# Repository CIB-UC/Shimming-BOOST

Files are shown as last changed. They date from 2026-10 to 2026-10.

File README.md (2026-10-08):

# BOOST — Low-Field MRI Shimming Tool

A plain-language guide.

**Who this is for:** anyone using this tool — you do **not** need to know programming.
This guide explains, in everyday language, what the tool does and the newest
things it can do. Every technical word is explained in the **Glossary** at the end.

For the deep technical details (architecture, config, code layout), see
[`docs/TECHNICAL_REFERENCE.md`](docs/TECHNICAL_REFERENCE.md). This
document is the friendly version.

**Getting started** (needs Julia and an NVIDIA GPU; once per computer, then each time you want the web page):

```bash
julia install_deps.jl      # one-time setup
julia gui/server.jl        # then open http://localhost:8010
```

---

## 1. What the tool does, in 30 seconds

An MRI magnet needs a very even magnetic field in the space where the sample or
patient goes. Straight out of the box, the field is a bit lumpy. We smooth it out by
placing lots of small magnets ("shims") in printed trays around the tube, and rotating
each one to just the right angle so their combined nudges cancel the lumps.

The tool does this in steps:

- **Stage 0 — Field map:** read a measurement of the current (lumpy) field.
- **Stage 1 — Optimize:** calculate the best angle for every shim magnet.
- **Stage 1.5 — Export:** write those results into a simple table (a list of magnets, positions, and angles).
- **Stage 2 — Inserts / STL:** turn that table into 3D files you can print.
- **Stage 3 — Verify:** look at the result in 3D.
- **Stage 4 — Python check:** an independent second opinion — a separate program
  recomputes the shimmed field and reports the score, pictures and spherical harmonics.

You normally drive all of this from a **web page** on your own computer: you start it
(a colleague can show you the one command), and it opens in your browser at
`http://localhost:8010`. Everything below is done by clicking in that page.

At the very top of the page there are two boxes: **Iteration name** and **Label #**.
Whatever you type there names your run — it becomes the output folder's name and the
number engraved on the printed trays. Set these first, every time.

---

## 2. The new features (overview)

1. **Insert search** — tell it how many magnets you own; it decides, one insert at a
   time, where each should go and how each magnet in it should be turned.
2. **OSII import** — you already have a magnet layout from the OSII program? Skip our
   calculation entirely and go straight to printing.
3. **Score on real measurements** — let the calculation judge the field using your
   actual measured points instead of a smoothed computer model. More honest.
4. **Faster ring search** — the "find the best magnet positions for me" tool now runs
   in minutes (or seconds) instead of the better part of an hour.
5. **Look at the field before shimming** — open the viewers on the raw measured field,
   with no magnets needed, to inspect how uneven it is up front.
6. **Magnet strength is now a setting** — type in your magnet's remanence and size
   instead of it being fixed in the code.
7. **Save a GIF of the result** — both viewers can now export an animated GIF of what
   you're looking at, so you can share it without asking someone to run the tool.

8. **Independent Python check (Stage 4)** — a separate program double-checks the result
   with its own physics, so you don't have to trust the optimizer's own arithmetic.

9. **Spherical-harmonic breakdown of the measured field (Stage 0)** — see which "field
   shapes" make up the unevenness, and optionally rebuild the field from only the first few
   degrees or only the biggest few shapes.

10. **Frames made explicit** — the magnet list is now turned back into your scanner's own directions,
    and both viewers draw (and sign) the field the same way. Plus **Halbach test bits** to check your axes.

Each is explained in full below.

---

## 3. Feature 1 — Insert search (place one insert at a time)

### What it's for

The ring search fills a whole **ring** at once — all 12 trays, 84 magnets. That is a
lot of magnets, and you may not have that many. Insert search works in the unit you
actually buy and print: **one insert** — one tray at one ring position, holding 7
magnets.

You tell it how many magnets you have. It works out how many full inserts that is
(magnets ÷ 7, rounded down — an insert is never planned half-empty), and then places
them one at a time.

### How it decides

1. It tries every empty, legal slot — every tray at every candidate ring — and for
   each one works out the best rotations for its 7 magnets.
2. It keeps the single best slot and fixes it in place.
3. It then treats those 7 magnets as **part of the magnet**, not as something still
   being decided, and goes looking for the next insert against that new situation.

So each insert is chosen knowing exactly what the previous ones did. Earlier inserts
are never re-turned, which is what makes this different from the ring search.

### The spacing rule

Two inserts **in the same tray** must have at least a few empty ring slots between
them (setting: `insert_search_min_spots_between`), because they'd otherwise collide.
Inserts in *different* trays are separate printed pieces, so they can sit at the same
ring position with no problem.

### Something important about using all your magnets

A shim magnet can be **rotated, but not switched off**. So adding one more insert is
not automatically an improvement — sometimes the extra magnets do more harm than good.

The tool therefore places your whole budget, records the score after every single
insert, and then tells you which point was actually best. If inserts 10 to 12 made
things worse, it says so, and the layout it hands you contains only the first 9. You
use fewer magnets *and* get a better field.

### How to use it — step by step

1. Open the web page and set **Iteration name** and **Label #** at the top.
2. Run **Stage 0 "Prepare field map"** as usual.
3. In the **"1 — Optimize"** box, pick the **"Insert search (per-slot)"** task.
4. Type your magnet count into **`magnets_available`**. The line underneath tells you
   how many full inserts that is, and how many magnets would be left over.
5. Click **"Run optimization."** Watch the log: one line per insert, showing where it
   went and the score afterwards.
6. When it finishes, read the **BEST PREFIX** line — that is what it kept.
7. Go to **"2 — Inserts / STL"** and click **"Build STL only."**

### Where to see what it decided

- The **"3 — Verify & output"** box lists each printed ring *and which trays actually
  carry magnets* — so you can see at a glance that, say, Ring_N07 holds only trays 2 and 7.
- `InsertSearch/insert_search.png` plots the score against the number of inserts, with
  the best point marked.
- `InsertSearch/insert_search.csv` lists every step, with a `kept` column.

---

## 4. Feature 2 — Importing an OSII layout

### What it's for

Sometimes another program (called **OSII**) has *already* decided where the magnets go
and how each should be rotated. In that case you don't need our tool to figure it out —
you only need to turn OSII's answer into printable trays. This feature does exactly
that, letting you jump in near the end of the process.

### What it actually does

It reads OSII's file and rewrites it in the format our tray-builder understands. Think
of it as a translator between two languages that describe the same thing.

### Why a translation is needed (the honest details, in plain terms)

OSII and our tool both locate each magnet with three numbers (like describing a spot by
its left–right, up–down, and front–back distances), and both give each magnet a
rotation angle. But they don't label the directions the same way, and they use
different units. So the tool automatically:

- **Converts the units** — OSII uses metres, we use millimetres (every distance is
  multiplied by 1000).
- **Matches up the directions** — one axis is the same in both; the other two are
  swapped, and one is flipped. The practical result: the ring of magnets OSII describes
  lands in the correct plane in our system, at its real, physical tray-slot number —
  positive going toward the wall end, negative going toward the gaussmeter end,
  counted outward from the centre of the tube.
- **Adjusts each magnet's rotation** — the two programs measure a magnet's turn from a
  different starting line **and** in opposite directions, so the tool flips the turn and
  adds a fixed quarter-turn (90°).

You don't do any of this by hand. But two settings let you correct the rotation if a
test print ever comes out turned the wrong way:

- **`osii_invert_angle`** (on by default) — flips the *direction* of the turn. If the
  magnets look **mirrored**, toggle this.
- **`osii_angle_offset_deg`** (90 by default) — the fixed extra turn. If every magnet
  looks rotated by the **same amount**, change this number.

Both are adjustable right in the web page, so a fix is a click away — no code.

### How to use it — step by step

1. Open the web page.
2. At the top, type your **Iteration name** and **Label #**. These will appear on the
   output folder and be engraved on the trays.
3. Find the box labelled **"1.5 — OSII import."**
4. In **"Use OSII file,"** pick your OSII file. (Not listed? Paste its full path into
   **"Import CSV (full path)"** and click **"Import into OSII folder"** — then pick it.)
5. Leave the **Transform** settings at their defaults the first time (invert on, offset 90).
6. Click **"Convert OSII → shim CSV."**
7. Go to the box labelled **"2 — Inserts / STL"** and click **"Build STL only."**
8. Your printable trays appear in the output folder, named with your iteration.

### Important: which Stage 2 button to press

Stage 2 has **two** buttons:

- **"Build STL only"** — use this after an OSII import (the magnet list already exists).
- **"Export + build STL"** — use this only after you've run our optimizer.

If you press "Export + build STL" after an OSII import, it will fail with a
"file not found" error — because that button first tries to export an optimizer result
that doesn't exist (you skipped the optimizer on purpose). **After OSII import, always
use "Build STL only."**

---

## 5. Feature 3 — Scoring on your real measurements

### The idea

Before the tool can improve the field, it has to measure how uneven the field is. It
checks the field at many points on the surface of an imaginary sphere (called the
**shell**) the size of your imaging region. There are now two ways to get those check
points:

- **`measured`** (new, and now the default) — use the *actual* points your scanner
  measured, with their *actual* readings. Nothing is invented or smoothed.
- **`sh_fibonacci`** (the older way) — build a smooth mathematical model that best fits
  your measurements, then read that model at a set of evenly spaced, invented points.

### Why "measured" is usually better

The smooth model quietly rounds off the sharpest bumps in the real field. On your last
scan, the smoothed version reported the field spread as about **18,050 ppm**, but your
real measured points showed about **18,255 ppm** — the smoothing was hiding roughly
**200 ppm** of genuine unevenness. It's better to improve the field against the honest
number. And because your scan already sits neatly on the sphere, using the real points
is both possible and more faithful.

**When would you keep `sh_fibonacci`?** If your measurement is scattered or doesn't sit
on a clean sphere, or if you specifically want a set of perfectly evenly spaced points.

### How to use it

In the **"0 — Field map"** box, under **"Field adapter,"** set **`shell_source`** to
`measured` (it's already set for you). Click **"Prepare field map."** You'll see a line
in the log like `shell: 1742 MEASURED points (no interpolation)`. Then run the optimizer
as usual. If instead you see `... SH-fit points ... (interpolated)`, you're on the old
mode — switch the dropdown.

---

## 6. Feature 4 — A faster "ring search"

### What ring search is

Instead of *you* choosing which tray positions ("rings") to fill with magnets, ring
search tries combinations and reports the best set. It has two styles:

- **Exhaustive** — literally tries *every* possible combination. Thorough, but slow.
- **Paired** — only tries *symmetric* layouts, where every ring on one side of the
  centre has a twin at the same number on the other side (for example rings −10, −5, +5
  and +10). You say how many rings you want in total (it must be an even number: 4 rings
  = 2 pairs), and it tries **every** possible combination of pairs. Because it only
  considers symmetric layouts there are far fewer to try (300 for 4 rings across ±25),
  so it is quick and thorough at once. The individual magnets are still turned freely —
  only the *ring positions* are paired. Two twins are exactly mirror images in
  distance only if the front and back tray distances are equal.
- **Greedy** — builds the set up one ring at a time, always adding the most helpful
  next ring. Almost always lands on the same (or nearly the same) answer, much faster.

### What was slow, and what we fixed

Trying every group of 4 rings out of 50 candidates is about **103,000 trial fits**, and
each was taking around 26 milliseconds — so the whole thing would run about **45
minutes**. We fixed two things:

- The trial fits were running in a slower numeric mode; we switched to the fast one.
- The big win: each trial was checking the field at all 1,742 points, but for merely
  *ranking* which group is best, a few hundred points give the same ordering. So ranking
  now uses about 250 points, and only the single winning group is re-checked on the full
  set. That's roughly **10–35× faster** per trial, with no meaningful change to the
  answer.

Exhaustive now takes about **3–5 minutes** instead of 45.

### The practical advice

For a search this size, **use "greedy."** It does about 200 trials instead of 103,000 —
so it finishes in **seconds** — and almost always finds the same answer. Choose it in
the **"1 — Optimize"** box: pick the **"Ring search (best n)"** task and set the method
to **greedy**. Only use exhaustive if you specifically need the guaranteed-best group.

### Watching it run

While it works, the log now prints `1000 scored`, `2000 scored`, and so on, so you can
see progress. (Previously a display quirk hid these updates until the very end — that's
fixed.)

---

## 7. Feature 5 — Looking at the field — before or after shimming

### What it's for

You don't have to shim before you can *see* the field. The two viewers now open on the
**raw measured field** on their own, so you can check how uneven it is right after
measuring — before deciding anything. (Once you've shimmed, the same viewers also show
the shimmed result, as before.)

### The two viewers

- **Slice viewer** — a flat "map" of the field through a chosen plane, plus a line
  profile across it and a homogeneity number (ppm). Best for judging uniformity.
- **3D viewer** — a 3-D cloud of the field (and, once shimmed, the magnets too).

### How to open the field on its own

1. Run **Stage 0 "Prepare field map."**
2. In the **"3 — Verify & output"** box, click **"Open slice viewer"** (or "Open 3D
   viewer"). With no shim yet, they come up showing only the measured field — the title
   says "pre-shim." No optimization, no magnets required.

### Handy tools inside the slice viewer

- **Zoom into a region** (drag/scroll) to focus on the client's region of interest. The
  zoom now **stays put** when you move the sliders, the **ppm updates to that region only**
  (it says "visible region"), and the line profile **clips to the region** too — so you're
  always looking at just the part that matters.
- **Sphere mask:** a button crops the view (and the ppm) to a sphere of a chosen radius,
  hiding the corners that are usually the least trustworthy.
- The field is now sampled every **5 mm** for smoother pictures.

---

## 8. Feature 6 — Saving a GIF of the result (new)

### What it's for

Once you've got a view you like in the 3D viewer or the slice viewer — a good angle,
a good slice, the shimmed result — you can save it as an animated GIF instead of
taking a screenshot or asking a colleague to open the tool themselves.

### The two kinds

- **3D viewer** — "Save GIF" spins the camera a full 360° around the bore at
  whatever elevation/distance you've currently zoomed/rotated to, and saves that
  as a GIF.
- **Slice viewer** — "Save GIF" instead sweeps the slice position across the field
  (a "slice sweep"), so you see the field change plane by plane.

Each viewer also has a second button, **"Save GIF pair: Measured vs Shimmed,"**
which saves two matching GIFs side by side — one of the raw measured field, one of
the shimmed result — for a clean before/after.

### Where the files go

GIFs are saved under your iteration's output folder, in a `Viewers` subfolder
(`data/outputs/Optimizer_Output_per_Iteration/<your iteration>/Viewers/`). Two settings control
length: how many frames, and how many frames per second — by default a GIF is
120 frames at 20 frames/second, i.e. 6 seconds long.

---

## 9. Feature 7 — Independent Python check (Stage 4)

### What it's for

The optimizer predicts a score (ppm) for your magnet layout, but it uses its own
calculation to do so. Stage 4 hands the same layout to a **separate program** (written
in Python, in the `Shimming_verifier` folder) that calculates the magnets' field a
different way. If both programs agree, you can trust the number. On the reference run
the optimizer predicted about 9,480 ppm and the Python check found about 9,560 ppm
(the unshimmed field was about 18,540 ppm).

### What you choose

Only three things — everything else (magnet strength, size, units) is taken from the
settings you already made:

1. **Which field** — the measured scan to compare against. Leave it on
   *"same as Stage 0 field map"* unless you want a different scan.
2. **Which shim layout** — normally this run's magnet list (from the optimizer, the
   insert search or an OSII import). Untick *verifier_use_shim* to look at the measured
   field alone, without any shim magnets.
3. **What to run** — any of: 2D pictures of the field with vs without shim, an
   interactive 3D scene (opens in any browser), and the spherical-harmonic pyramids
   (how much of each "field shape" the shim removes).

### How to use it

1. Finish your run (you need a shim CSV, so at least Stage 1.5 or an insert search).
2. In the **"4 — Python verifier"** box, check the three choices above.
3. Click **"Run verifier."** It takes a few seconds; the log ends with the
   with/without-shim scores and where the files went.
4. Click **"Open verifier output"** to see the pictures and open `scene_3d.html`.

You can also make it run automatically at the end of a full run (*run_python_verifier*),
or run only this stage from the command line by setting `start_stage = 5`.

### First-time setup

The Python program needs a few Python packages. Once, in a terminal:
`python -m pip install -r stages/stage4_verifier/Shimming_verifier/requirements.txt`. If Python isn't on
your PATH, put its full path in *verifier_python*.

---

## 9a. Feature 9 — Spherical-harmonic breakdown at Stage 0

### What it's for

Any uneven field can be split into standard "shapes" called spherical harmonics, each with
a *degree* n (1 = a simple slope, 2 = a saddle/bow shape, then finer and finer detail) and a
strength in mT. Stage 0 now shows this breakdown for your measured field every time it
builds the field map, so you can see at a glance which shapes dominate — and therefore what
the shims actually have to fight.

### What you see

In the run log, after Stage 0: the average field, a short table of how strong each degree
is, and **a list of the 5 biggest shapes** (say how many with *sh_top_k*), each with its
share of the total unevenness. A full table is saved next to your results
(`SHDecomposition/sh_decomposition.csv`).

### What you can choose (*sh_select*, Stage 0 → Field adapter)

- **all** (default) — use every shape the fit found. Nothing changes from before.
- **first_n** — keep only degrees 1…n (set *sh_use_degree*). Throws away the fine detail and
  keeps the broad shape.
- **top_k** — keep only the average plus the *sh_top_k* biggest shapes (for example 5).

With the last two, the optimizer and the viewers work on this **simplified** field, not the
raw measurement — so the ppm numbers you see afterwards describe the simplified field. The
log's last line tells you how far the simplified field is from your real data (RMS and ppm).
For the honest number, keep *all* and use the shim on the real field; use *first_n* / *top_k*
when you want to study or shim only the dominant shapes.

In shell mode with *shell_source = measured*, the same measured points are used, but their
values come from the simplified field when first_n / top_k is on.

---

## 9b. Feature 10 — Which way is the field pointing? (frames) and Halbach test bits

### The problem in plain words

Your scanner's axes (X, Y, Z) and the magnet's field direction don't have to line up. The tool
calculates in an internal "tidy" view where the field always points up (+y) — it quietly **turns** your
measurement to get there. Your scan says the field points along −y, so the tidy view is turned half a
turn (180°) compared with the scanner. That is fine for the maths, but the results (magnet positions and
angles) have to be turned **back** before they mean something in the scanner's own directions.

### What happens now (by default)

- Right after the optimizer, the magnet list is turned back into the **scanner's view** (`shim_csv_frame
  = "scan"`). The printed trays, both viewers and the Python check then all use the scanner's view.
- Both viewers draw in the scanner's view too (`viewer_frame = "scan"`) and show the field **with its sign**
  (negative numbers if the field points −x or −y). Set either key to `"optimizer"` (in `config.toml`) to get
  the old behaviour.
- A magnet list made **before** this change is not converted — just click **Export** again (no need to
  re-optimize).
- Tray numbers are worked out from where each magnet sits, so after the turn a −y scan's tray 3 becomes tray 9
  and so on (every tray shifts by 6). Check that the physical tray numbering on your magnet matches the
  scanner's directions — this is the one thing the tool cannot know for you.

### How well was it checked?

An independent calculation on your real −y scan showed the turned-back layout cuts the unevenness from
about 19,200 ppm to about 9,600 ppm, while using the un-turned list made it worse (about 28,800 ppm). It
cannot tell front from back (the rings are nearly symmetric), so a mirrored z axis would not show up. The
viewers and the export step themselves have not been run since this change.

### Halbach test bits (checking your axes without the optimizer)

`make_halbach_ring_csv.py` writes a small magnet list that imitates a Halbach ring, so you can see in the
viewers and the Python check whether directions come out as expected. You choose the OSII version (OSII2: field
+y, OSII1: field +x), which tray(s), where along the bore (a z in mm, or a slot number) and how many
positions (an odd number). To make STLs from it: copy it into a **new** iteration folder as `<iteration>_shim.csv`
and use **Build STL only**.

## 10. Glossary

- **Shim (shim magnet)** — a small magnet added to nudge the main field toward being even.
- **Ring** — one position along the tube where a full circle of shim magnets sits. In this setup a full ring holds 84 magnets.
- **Insert position (InsertPos)** — the real, physical slot number for a ring, counted
  outward from the centre of the tube: positive toward the wall end, negative toward
  the gaussmeter end (e.g. `-7` or `12`). This is what "Ring number" actually means
  everywhere in the tool now — it is never just a count of "which ring is this in
  the current run" — and it's what gets engraved on the printed part.
- **N / P label** — how a negative or positive insert position is written on a
  printed part and in folder/file names, since a printed minus sign is easy to
  misread or lose: `N07` means insert position `-7`, `P12` means `+12`.
- **Tray** — the 3D-printed holder that carries the magnets for one part of a ring.
- **Insert** — one tray's worth of magnets at one ring position: 7 magnets. The unit the insert search places, and the unit you print.
- **Front / Back** — Front is the gaussmeter end of the tube, Back is the wall end. Their distances from the centre are set separately, because the magnet isn't symmetric.
- **Bore / imaging region / DSV** — the tube (and the space inside it) where the sample or patient goes; the region we want to be even.
- **Field uniformity / ppm** — a score for how even the field is. "ppm" means *parts per million*. It's the gap between the strongest and weakest field, divided by the average, times a million. **Lower is better.**
- **Shell** — the surface of an imaginary sphere where we check the field. Thanks to physics, if the field is even on this surface, it's even everywhere inside — so checking the surface is enough.
- **Optimizer** — the part of the tool that calculates the best magnet angles.
- **Field map** — the tool's internal picture of the current field, built from your measurement.
- **CSV** — a plain table file, like a spreadsheet saved as simple text.
- **STL / STEP** — 3D-model file formats: STL for printing, STEP for CAD editing.
- **Iteration** — one named run. Its name labels the output folder and is engraved on the printed trays.
- **Stage 0 / 1 / 1.5 / 2 / 3 / 4** — the steps of the process: read the measurement (0), calculate angles (1), write the magnet list (1.5), make printable trays (2), view/verify (3), independent Python double-check (4).
- **magpylib** — the Python physics library the Stage 4 check uses to compute each magnet's field. Separate from the optimizer's own code, which is the point.
- **Spherical harmonics (SH) pyramid** — a chart splitting the field's unevenness into standard "shapes" (degree 1, 2, 3 …). Shows *which* shapes the shim removes and which remain.

- **Scan frame (scanner view)** — the X, Y, Z directions of your measurement file.
- **Optimizer frame (tidy view)** — the internal view where the field always points along +y; the optimizer works here.
- **Halbach ring** — magnets turned in a regular pattern (angle = twice the position angle) so their fields add up inside the ring.

---

## 11. Quick reference — where each new setting lives

| Setting | Where in the web page | Plain meaning |
|---|---|---|
| `shell_source` | Stage 0 → Field adapter | Use real measured points (`measured`) or a smoothed model (`sh_fibonacci`). |
| OSII file | Stage 1.5 → OSII import | Which OSII layout file to convert. |
| `osii_invert_angle` | Stage 1.5 → Transform | Flip magnet turn direction if a print looks mirrored. |
| `osii_angle_offset_deg` | Stage 1.5 → Transform | Fixed extra turn (90°); change if a print is rotated by a constant amount. |
| Ring search method | Stage 1 → Ring search task | `greedy` (fast, recommended), `exhaustive` (thorough, slow) or `paired` (only symmetric ±pairs, every combination). For `paired`, the ring count is the total and must be even. |
| `magnets_available` | Stage 1 → Insert search task | How many shim magnets you own. Divided by 7 to get the number of full inserts. |
| `insert_search_min_spots_between` | Stage 1 → Insert search task | How far apart two inserts must be *within the same tray*. |
| `magnet_Br_T` | Stage 0 → Shim magnets | How strong one magnet's material is: its remanence, in tesla (from the datasheet). |
| `magnet_side_mm` | Stage 0 → Shim magnets | The physical cube side length of one magnet, in mm. |
| `letter_thickness` | Stage 2 → Insert params | How deeply the label digits are engraved into the printed part. |
| `label_scale` | Stage 2 → Insert params | Overall size of the engraved label digits (iteration, insert position, tray). |
| `viewer_gif_frames` / `viewer_gif_fps` | (config.toml; not yet a GUI field) | How many frames a Save-GIF export has, and how fast it plays — together set the length in seconds. |
| `sh_select` | Stage 0 → Field adapter | Build the field map from `all` shapes, only the `first_n` degrees, or only the `top_k` biggest. |
| `sh_use_degree` | Stage 0 → Field adapter | first_n: keep degrees up to this number. |
| `sh_top_k` | Stage 0 → Field adapter | top_k: how many biggest shapes to keep — and how long the "biggest shapes" list in the log is. |
| `verifier_measurement` | Stage 4 → Which field | Scan the Python check compares against (blank = the same as Stage 0). |
| `verifier_use_shim` / `verifier_shim_csv` | Stage 4 → Which shim layout | Include the shim magnets; blank path = this run's magnet list. |
| `verifier_make_2d` / `_3d` / `_sh` | Stage 4 → What to run | Which outputs to produce: 2D pictures, 3D scene, spherical-harmonic pyramids. |
| `run_python_verifier` | Stage 4 → What to run | Also run Stage 4 automatically at the end of a full run. |
| `front_tray_shift_mm` | Stage 0 → Geometry | Distance from the centre to the first tray on the gaussmeter side. |
| `back_tray_shift_mm` | Stage 0 → Geometry | Distance from the centre to the first tray on the wall side. |
| `tray_slot_spacing_mm` | Stage 0 → Geometry | Gap between neighbouring tray positions (10 mm). |
| `main_field_direction` | Stage 0 → Field adapter | Which way the field points in your scan (`auto` reads it from the measurement). |
| `shim_csv_frame` | (config.toml only) | `scan` (default): the magnet list is written in your scanner's view; `optimizer`: old internal view. |
| `viewer_frame` | (config.toml only) | `scan` (default): viewers draw in your scanner's view with a signed field; `optimizer`: old view. |

All of these can also be set by editing the `config.toml` file directly, but the web
page is the easy way and is recommended.

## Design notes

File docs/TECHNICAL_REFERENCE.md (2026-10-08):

# Low-Field MRI Shimming Pipeline — Technical Reference

Passive-shimming toolchain for a low-field Halbach MRI magnet (Pontificia
Universidad Católica de Chile — Low-Field MRI project). It takes a measured
magnetic-field map, computes the optimal angles for a set of small permanent
"shim" magnets that flatten the field, and produces 3D-printable tray inserts —
all driven from a single config file or a browser GUI.

```
measured CSV ──▶ field map ──▶ optimal shim angles ──▶ shim CSV ──▶ STL/STEP trays
   Stage 0          Stage 1          (Stage 1)          Stage 1.5      Stage 2

 measured CSV + shim CSV ──▶ independent Python (magpylib) check of the result
                                         Stage 4
```

Everything is organized as one **iteration**: name it, set parameters, run, get
printable parts plus a verification view.

---

## Part I — Project information

**The problem.** A Halbach array gives a strong-ish B₀ in the bore, but it is not
homogeneous enough for imaging. Passive shimming corrects this by placing many
small magnets on trays around the bore; rotating each magnet changes its field
contribution. The task is to choose all the angles so the field over a target
volume is as uniform as possible.

**The measurement.** B₀ is measured on a spherical shell (or a grid) with a
gaussmeter on a robot. The pipeline reads that scan, models the field, and scores
homogeneity as **ppm** = 10⁶ · (max − min) / mean over the target region.

**The key scientific result.** The shim field is *exactly linear* in the magnet
moments, so field variance is a smooth, convex function of the angles with an
analytic gradient. A gradient method (L-BFGS) therefore finds the **global**
optimum in seconds — and shows that the remaining inhomogeneity is a **hardware
limit**, not an optimizer limit. The lever from here is physical: more / stronger /
closer shim magnets, or more rings.

**Three headline capabilities beyond "solve for the angles":**
- **Ring search** — instead of telling it where to put rings, ask it to *find* the
  best set of *n* rings from a candidate range.
- **Insert search** — a finer granularity: place ONE insert at a time (one tray at
  one ring, `mags_per_segment` magnets), driven by how many magnets you actually
  own, freezing each choice before searching the next.
- **Shell evaluation** — score homogeneity on a single spherical shell at the DSV
  radius. Because the bore field is harmonic, min/max on that surface equal min/max
  over the whole ball, so range/ppm is exact with far fewer points.

---

## Part II — How it works

### Quick start

```bash
julia install_deps.jl        # once — pins the project (CUDA, GLMakie, Gmsh, Optim, HTTP, JSON, …)

# Option A — the GUI (recommended)
julia gui/server.jl          # opens http://localhost:8010

# Option B — terminal, one config-driven run
julia run_pipeline.jl        # runs Stage 0→1→1.5→2→3 (viewers)→4 per config.toml
```

Needs an NVIDIA GPU (CUDA) for Stage 1 and the viewers. Everything is driven by
**`config.toml`**; `pipeline_config.jl` reads it and derives every path + geometry,
so nothing can drift apart.

### The stages

| Stage | Script | Does |
|---|---|---|
| 0 | `Field_data_*` adapters | measured CSV → field map (`.jld2`) |
| 1 | `sim_annealing_optim/` **or** `grad_optim/` | field map → optimal shim-magnet angles |
| 1.5 | `export_csv.jl` | optimizer result → shim CSV (`X, Y, RingNumber, Angle`; `RingNumber` = real InsertPos) — the seam |
| 2 | `CSV_to_STL.jl` (Gmsh) | shim CSV → per-tray STL + STEP, + the static insert |
| 3 | `Shimming_magnets_visualizer.jl`, `field_slice_viewer.jl` | 3D magnet/field view, 2D slice + profile; each has a "Save GIF" button |
| 4 | `python_verifier.jl` → `stages/stage4_verifier/Shimming_verifier/run_verifier.py` | independent **Python/magpylib** re-computation of the shimmed field: ppm, 2D projections, 3D scene, spherical-harmonic pyramids |

`run_pipeline.jl` chains them as separate subprocesses (so CUDA/GLMakie and Gmsh
never share a process), checks each exit code + output, and stops at the first
failure. `start_stage` lets you jump in and reuse earlier outputs.

**Two shortcuts that skip the optimizer:** `osii_to_shim.jl` converts an existing
**OSII** magnet layout straight into the Stage-1.5 shim CSV (then Stage 2 runs as usual —
GUI button "Build STL only"), and both **Stage-3 viewers run with no shim CSV** — after
Stage 0 alone they show just the measured field (pre-shim) for homogeneity inspection.

### Stage 4 — independent Python verifier (`Shimming_verifier/`)

A self-contained Python tool (magpylib closed-form cuboid model — **no shared code with
the Julia kernels**) that takes the measured field and the shim layout, recomputes the
shim's field at the measured points, and reports the shimmed homogeneity. Because it is
a different model of the same magnets, agreement with the optimizer's ppm is a genuine
cross-check of the operator `G` (reference run: optimizer predicted 9483 ppm, verifier
9562 ppm, unshimmed 18538 ppm). It stays independent of the pipeline: it needs only
**which field, which shim layout, what to run**, and lives in its own folder
(`main.py` = interactive/VSCode entry, `run_verifier.py` = command-line entry, deps in
`requirements.txt`).

`python_verifier.jl` is the thin adapter (Julia stdlib only — no CUDA, no field map):
- **Inputs** — `verifier_measurement` (blank = the run's own scan) and the shim CSV
  (`verifier_use_shim`; blank `verifier_shim_csv` = this iteration's `_shim.csv`, i.e.
  whatever produced the seam: optimizer export, insert search or OSII import). The
  seam's `RingNumber` (the real InsertPos) is converted back to axial z with
  `ringpos_from_tray_mm` and the current tray-geometry keys; a CSV that already has a
  `Z (mm)` column (e.g. `export_csv.jl`'s `_shim_xyz.csv`) is accepted as-is.
- **What to run** — `verifier_make_2d` / `_3d` / `_sh` (+ `verifier_sh_max_degree`,
  `verifier_show_figures`).
- **Not repeated** — magnet strength/size come from `magnet_Br_T` / `magnet_side_mm`,
  the coordinate unit from `sh_measured_unit_mm`.
- **Frame.** Stage 0 rotates the scan so B0 → +y for the optimizer, so every shim CSV is
  in that frame, while the verifier reads the *raw* scan. `run_verifier.py
  --shim-frame optimizer` rotates the shim positions + angles back into the scan's frame
  using B0's direction (`main_field_direction`, or auto-detected from the scan's mean
  field vector). Identity for the current scanner (B0 = +y); checked with synthetic
  +x / −x / −y scans, which reproduce the +y result exactly. **Now** (`shim_csv_frame = "scan"`, the
  default) the seam CSV is already in the scan frame, so `python_verifier.jl` passes `--shim-frame lab`
  (CSV as written); with `"optimizer"` it still passes `--shim-frame optimizer`.
- **Outputs** → `data/outputs/Optimizer_Output_per_Iteration/<ITER>/PythonVerifier/`
  (`comparison_2d.png`, `scene_3d.html`, `sh_pyramid.png`, plus the derived shim input).
- **Running it** — GUI Stage 4 "Run verifier"; `julia stages/stage4_verifier/python_verifier.jl`;
  `start_stage = 5` (verifier only); or `run_python_verifier = true` to append it to a
  full run. Misalignment-study knobs (remanence spread, measurement/magnet shifts) exist
  on the CLI (`stages/stage4_verifier/python Shimming_verifier/run_verifier.py --help`) but default to 0.

### Stage 0 — reading the measurement

A shared reader, `utils/read_measured.jl`, handles **two spherical-scan CSV
formats** transparently:
- **simple** — metadata line 1, header line 2 (`X,Y,Z,Gauss`) — the original Josh scan;
- **"Controlled"** — a multi-line metadata block, then columns for `radio, theta,
  phi, X,Y,Z, T_robot, muestra, …, x/y/z axis (gauss), Magnitude (gauss)`.

It finds the data header wherever it is, **averages the repeated samples per point**
(`muestra`), uses `|B|` (the `Magnitude` column), and — when the scan recorded field
components — returns the mean `(Bx,By,Bz)` vector. Temperature is read but not used
yet.

Three Stage-0 adapters consume that:
- **`Field_data_file_adapter.jl`** (`field_adapter = :reshape`) — a complete regular
  (parallelepiped) grid; just reshapes it.
- **`Field_data_SH_interpolator.jl`** (`:spherical_harmonics`) — fits regular solid
  spherical harmonics to a shell/scattered scan, evaluates on a **cube grid**.
- **`Field_data_shell.jl`** (`eval_domain = :shell`) — the optimizer's shell at Rmax.
  `shell_source = "measured"` (default) feeds the **raw measured points + measured |B|**
  directly — no interpolation, the honest choice when the scan already sits on the Rmax
  sphere; `"sh_fibonacci"` instead evaluates the SH fit on a **Fibonacci sphere** of
  `shell_n_points`. Either way it *also* writes the cube grid (`sh_grid_n` pts/axis) so
  the viewers still work.

**Spherical-harmonic decomposition + selection (SH and shell adapters).** Both SH-based
adapters already fit `B ≈ Σ a_{n,m}(r/Rn)^n Y_{n,m}` (degree `sh_degree`). Stage 0 now
always **prints the decomposition** — mean field, per-degree strength, and the `sh_top_k`
(default 5) largest `|a_{n,m}|` with `n ≥ 1` and their share of the energy — and writes every
coefficient to `data/outputs/Optimizer_Output_per_Iteration/<ITER>/SHDecomposition/sh_decomposition.csv`
(`n, m, a_full, a_used, rank, kept`). `sh_select` then chooses what the **field map is built
from** (kept columns are *re-fitted* to the data, not just truncated):

| `sh_select` | field map built from |
|---|---|
| `"all"` (default) | every degree 0..`sh_degree` — the original behaviour, bit-for-bit unchanged |
| `"first_n"` | degrees 0..`sh_use_degree` only (smooths away high-order detail) |
| `"top_k"` | the mean + the `sh_top_k` largest coefficients only (dominant harmonics) |

With `first_n` / `top_k` the optimizer and both viewers see the **filtered** field. In shell mode,
`shell_source = "measured"` then means *the measured points, with SH-filtered values* (with
`"all"` it is still the raw measured `|B|`); `sh_fibonacci` simply evaluates the filtered fit.
The saved jld2s also carry `c_full`, `sel_cols`, `sh_select_name`. Coefficients live in the
**optimizer frame** (B0 → +y), so `m` differs from the Stage-4 pyramid (raw lab frame) whenever
the scanner's B0 isn't already +y. Logic: `utils/sh_select.jl` (stdlib-only, unit-testable).

**Auto direction.** Set `main_field_direction = "auto"` and the SH/shell adapters
detect B₀'s axis from the measured field vector (the dominant in-plane component).
Otherwise use an explicit `+x/-x/+y/-y`. The direction only sets how coordinates
rotate into the optimizer frame (B₀ → +y); the stored field is `|B|`.

### Coordinate frames (scan vs optimizer) — where the rotation happens

Three frames exist; the pipeline converts between the first two only.
- **Scan (lab) frame** — the measured CSV's own `X, Y, Z`. B0 points along whatever
  `main_field_direction` says (`+x/-x/+y/-y`, or `auto` = the dominant in-plane component of the
  mean field vector the probe recorded).
- **Optimizer frame** — Stage 0 rotates the scan **about the bore (z)** so B0 → +y
  (`lab_to_optimizer_xy`: `+x → (−y, x)`, `−x → (y, −x)`, `−y → (−x, −y)`; z untouched). The field is
  stored as |B| (positive), so no vector is rotated and the sign is dropped. The operator `G`, the
  optimizer, the result jld2s and the field maps all live here. The resolved direction is saved in the
  field-map jld2 as `field_direction`.
- **Physical tray frame** — Stage 2 numbers trays from the CSV's X, Y (`assign_tray`: tray 12 → +y,
  9 → +x, 6 → −y, 3 → −x). It is **not** converted anywhere: it simply takes the CSV's frame to be the
  magnet's. Whether that is right depends on where tray 12 physically sits relative to B0 / the scan axes
  (open question).

**Rotating back (new).** Two settings in `config.toml`, both default `"scan"`:
- `shim_csv_frame` — frame the shim CSV is **written** in. With `"scan"`, `export_csv.jl` (both
  `_shim.csv` and `_shim_xyz.csv`) and `grad_optim/insert_search.jl` rotate positions **and** moment angles
  back by the scan's B0 direction right after the optimizer (`+x`: (x,y)→(y,−x), angle −90°; `−x`:
  (−y,x), +90°; `−y`: (−x,−y), +180°). Stage 2 STLs, both viewers and the Stage-4 verifier then work in the
  scan frame; Stage 2 re-derives the tray from the rotated X, Y (tray *t* → *t*+6 for a −y scan). Result
  jld2s, operators and field maps stay in the optimizer frame. `"optimizer"` = the old behaviour.
  Hand-made CSVs (OSII import, `make_halbach_ring_csv.py`) are used as written, in whichever frame this
  key declares. **CSVs written before this change are not converted — re-run Stage 1.5 export.**
- `viewer_frame` — frame the **Stage-3 viewers draw** in. `"scan"`: the field grid + axes
  (`utils/viewer_frame.jl: grid_to_scan`) and the magnets are rotated back for display, and the field is
  shown **signed** (negative for a `−x/−y` scan, label "B (mT), B0 along −y"). `"optimizer"`: |B|, B0 → +y.
  Display-only; the dipole field is still computed in the optimizer frame, then rotated.
Neither key has a GUI field yet (`config.toml` only; `gui/backend.jl` validates the values).

### Evaluation domain — grid vs shell

`eval_domain` chooses where the gradient optimizer + ring search score:
- **`"grid"`** (default) — a dense Cartesian grid; the ∇B/Tikhonov term is available,
  and the SA optimizer + viewers use this.
- **`"shell"`** — a single spherical shell at `Rmax`. Exact range/ppm with far fewer
  points; the ∇B term is disabled; gradient + ring search only. `setup_shell.jl` feeds
  the shell points as the evaluation set. `shell_source` picks those points:
  **`"measured"`** (default) scores the raw measured points + measured |B| (no
  interpolation); **`"sh_fibonacci"`** resamples the SH fit onto `shell_n_points` uniform
  points — smoother, but hides sharp extrema (measured scored ~200 ppm higher than the
  SH-smoothed shell on the reference scan).

### Stage 1 — two optimizers + ring search

The field is exactly linear in the moments:
`By = By_base + Gx·(μcosθ) + Gy·(μsinθ)` (operator `G` validated to rel. err ≈ 4e-8).

**Simulated annealing — `sim_annealing_optim/`.** The original BOOST optimizer;
minimizes `w·(max−min) + λ·√mean|∇B|²` by annealing. Kept as a baseline and for the
λ (Tikhonov) sweep. Files: `run_optim.jl`, `run_lcurve.jl`, `benchmark.jl`,
`operation.jl`.

**Gradient optimizer — `grad_optim/`.** Because the field is linear, variance /
soft-range / the ∇B penalty are smooth with analytic gradients, so **L-BFGS finds
the global optimum in seconds** (10/10 identical restarts). Two phases, split by the
cached operator `operator_G.jld2`:
- `optim_grad.jl` (GPU) — build + cache the linear operator `G`.
- `run_grad.jl` (CPU) — minimize `data_term + grad_lambda·mean|∇B|²` with L-BFGS.
- `run_grad_lcurve.jl` — sweep `grad_lambda` → range-vs-gradient L-curve (overlaid on SA).
- `grad_math.jl` — pure shared math; `grad_core.jl` — binds it to the cached operator.
- Objective knobs: `grad_data_term` (`:variance` / `:softrange`), `grad_softrange_beta`,
  `grad_lambda`.

**Shim-magnet strength.** Two numbers, `magnet_Br_T` + `magnet_side_mm` in
`config.toml`: the magnet's **remanence** Br (T, a material property from the
datasheet or your own measurement setup, independent of size) and its physical
cube side length (mm). `pipeline_config.jl` converts these to the dipole moment the
kernels consume — `μ = Br·side_m³/μ0` (`μ0 = 4π×10⁻⁷`) — and the optimizer, ring
search, insert search and **both viewers** all read it; it used to be hardcoded, in
two different units, in five separate files, then briefly lived as a single
on-axis-field-at-1cm proxy (`magnet_B1cm_mT`) before being replaced by the Br/side
pair now that Br is measured/calculated consistently for the actual 6×6×6 mm
magnets. (`magnet_B1cm_mT`/`B1CM_T` still exist internally as **derived, back-compat**
constants — reporting what on-axis field at 1 cm this Br+geometry implies, for
`utils/imanes.jl`'s calling convention — but are no longer config inputs.) Changing
either value invalidates the cached operator; `grad_core.jl` warns if the cache
disagrees with the config. `initial_angle_deg` (the SA's start point and the angle
`optim_grad` validates `G` at) sits beside it.

**Axial tray geometry.** The two ends of the bore are anchored independently, since
they need not be symmetric:
`z(+n) = +(back_tray_shift_mm + (n−1)·tray_slot_spacing_mm)` toward +Z ("Back — Wall"),
`z(−n) = −(front_tray_shift_mm + (n−1)·tray_slot_spacing_mm)` toward −Z ("Front —
Gaussmeter"). Tray 0 does not exist. This replaces the old symmetric `half_shift_mm`
(`h` at spacing `s` ≡ `front = back = s − h`); 10/10/10 reproduces `half_shift_mm = 0`
exactly. Both Stage-3 viewers now read these from config — they used to hardcode
`half_shift_mm = 0.0` and so drew magnets at the wrong z for any non-zero shift.

**Ring search — `grad_optim/ring_search.jl`.** Finds the **best set of *n* rings**
instead of you specifying them. Each candidate ring's field response is a fixed
block of `G` columns, so it builds the operator once for all candidate rings
(cached `ring_operator.jld2`), then scoring any subset is a small variance solve.
- `method = :greedy` — forward selection, `n·N` solves; scales to any *n*.
- `method = :exhaustive` — all `C(N,n)` subsets, guarded by `ring_search_max_combos`.
- `method = :paired` — only **symmetric** sets: `ring_search_n` is the *total* (even) and
  the rings come as `n/2` pairs `{−a, +a}` (same tray number either side of z = 0), e.g.
  `[-10, -5, 5, 10]`. It tries **every** choice of `n/2` pair magnitudes,
  `C(#pairs, n/2)` sets (300 for n=4 over ±25; 2 300 for n=6; 12 650 for n=8), guarded by
  `ring_search_max_combos`. Only the *positions* are paired — every magnet's angle is still
  free. Pairing is by tray number, so it is an exact z-mirror only when
  `front_tray_shift_mm == back_tray_shift_mm`. The usual `min_sep` / `min_spots_between`
  rules still apply (so with the default 3, a = 1 and adjacent pairs like ±5, ±6 are skipped).
  Needs a range symmetric about 0; `ring_search_n_max` (default 8) still caps the total.
  Writes `ring_search.csv` (top 50 sets) + a ranked plot; `ring_search_apply` works as usual.
  Enumeration lives in `grad_optim/ring_combos.jl` (pure, unit-testable).
- Rejects rings closer than `ring_search_min_spots_between` empty tray spots.
- Writes CSV + plot; `ring_search_apply` writes the winner into
  `positions_in_tray_new_wished` and saves the standard result so Stage 2 can run.

**Insert search ranking mode.** `insert_search.jl` has a local `RANK_FULL_SHELL`
toggle: `false` ranks every candidate slot cheaply on a ~250-point sub-shell and
re-solves only the winner on the full shell (the ~30× faster mode, described
below); `RANK_FULL_SHELL = true` (current default in the file) instead ranks
**every** candidate on the full shell — an accuracy/speed check on whether the
subsample ever picks a different "best slot" than scoring against everything.
Cost scales with `Ns/RANK_NS` per round (e.g. 1742 vs 250 ⇒ ~7× slower ranking),
so expect a full-shell run to take noticeably longer per insert; flip it back to
`false` for routine fast placement once the two modes have been cross-checked.

**Insert search — `grad_optim/insert_search.jl`.** Same linear algebra, finer unit.
A candidate slot is one **insert**: one tray at one ring, holding `mags_per_segment`
magnets. Because a ring's operator block already contains every tray's columns, an
insert is just an `MPS`-column slice — so this **shares `ring_operator.jld2`** with
the ring search (identical `SIG`; whichever runs first pays the one-time GPU build).

The loop is *frozen sequential placement* (matching pursuit), not the ring search's
greedy: each round scores every free legal slot against the **current** base field,
picks the best, re-solves it on the full shell, then **freezes its angles and folds
its field into the base** before the next round. Placed angles are never revisited,
so every solve is `MPS` variables no matter how full the bore gets — cost per round
is flat.

- **How many:** `magnets_available ÷ mags_per_segment`, rounded down. Every insert is
  assumed FULL; a remainder is reported and left unplaced.
- **Spacing:** two inserts in the *same tray* need at least
  `insert_search_min_spots_between` empty ring slots between them. Different trays are
  separate printed pieces, so they are unconstrained. (`spots_between` discounts the
  non-existent tray 0; `ring_search` uses the simpler `|a−b|−1`.)
- **Fixed-magnitude caveat:** a magnet can be rotated but not switched off, so ppm is
  *not* guaranteed to fall monotonically. It places the whole budget, logs ppm at each
  step, and reports the best **prefix** — publishing only that prefix.
- **Output:** a *sparse* shim CSV plus a standard result jld2 whose `final_state`
  carries the sparsity (1 = insert placed, 0 = empty slot). That mask is what lets the
  rest of the pipeline treat it normally — `eval_metrics` scores it, and `export_csv`
  regenerates the same sparse CSV rather than a dense one.
- Segment index ≠ tray number: the tray is re-derived from (x,y) exactly as
  `CSV_to_STL` does, so the spacing rule and the printed `Ring_<InsertPos>/Tray_T`
  agree.

**RingNumber = real, physical InsertPos (not a sequential index).** The shim CSV's
`RingNumber` column, `p.ring` throughout the code, and the `InsertPos` argument
`utils/helping_functions_for_JIG.jl`'s `make_label` engraves on the printed part are
all **the same number**: the actual signed tray slot (e.g. `-7`), not a 0-based
position in whatever ring set the current run happens to use. Every stage that
produces or consumes RingNumber (`export_csv.jl`, `insert_search.jl`,
`osii_to_shim.jl`, `CSV_to_STL.jl`, the GUI, both Stage-3 viewers) derives it
directly from the physical value — never by zipping a sorted/enumerated list against
`positions_in_tray_new_wished` positionally, since that array's order need not match
a CSV's ring order and a CSV's ring set can differ from the current config's (an
OSII import, a sparse insert-search result, or a re-run under a different config).
Printed parts and folder/file names spell the sign as a **letter token**, `N`/`P`,
rather than a literal `+`/`-` (fragile to engrave/type reliably) —
`insertpos_label(pos) = (pos<0 ? "N" : "P") * lpad(abs(pos), 2, '0')`, e.g. `-7 →
"N07"`, `12 → "P12"` — duplicated locally in each file per the codebase's existing
convention of small local helpers over a shared-utils import for this kind of thing.

### Metrics & verification

- `utils/eval_metrics.jl` — range / ppm / mean By / gradient-RMS for **any** saved
  result (SA or gradient), side by side with a no-shims baseline, identical
  definitions.
- `utils/verify_solution.jl` — independently re-checks a result on the GPU.
- Every gradient solve runs a finite-difference gradient self-check at startup.
- **GIF export (both Stage-3 viewers).** Each viewer has a single-view "Save GIF"
  button and a "Measured vs Shimmed" pair-comparison button: the 3D viewer records a
  360° rotating-camera GIF at its current elevation/distance, the slice viewer
  records a slice-sweep GIF. Both use `Makie.record(...)` **explicitly qualified**
  (never the bare `record`), because CUDA and GLMakie both export a conflicting
  `record` binding and the unqualified name is ambiguous once both packages are
  loaded. Config: `viewer_gif_frames` (frames/GIF), `viewer_gif_fps`, and
  `viewer_gif_subdir` (default `"Viewers"`, saved under
  `data/outputs/Optimizer_Output_per_Iteration/<ITER>/Viewers/`); length in seconds =
  `viewer_gif_frames / viewer_gif_fps`.

### Configuration (`config.toml`)

The only file you edit for a run. Grouped: run mode / optimizer / eval_domain,
iteration identity, shared geometry, Stage-2 insert params, SA params, gradient
objective, SA sweep, ring search, Stage-0 adapter, Stage-3 viewers. Conventions:
enums are strings (`optimizer = "grad"`), seed ranges are `[lo, hi]`, arrays are
TOML arrays. `pipeline_config.jl` reads each key with a typed accessor and derives
all absolute paths.

**Presets** (`gui/presets.json`): named geometry and Stage-2 insert setups —
`OSII V1.1` and `OSII V2.1 (PUC trays)` (default V2.1). A Stage-2 version pins tray
radii, inter-magnet angle, and magnet radius together.

### The GUI (`gui/`)

A local web app, no build step. `julia gui/server.jl` serves `app.html` on
`localhost:8010` and a JSON API over `backend.jl`. Header reads "BOOST — B0
Optimization Shimming Technique" / "Low Field MRI Project UC", styled with a
light-green themed palette (`--bg`/`--acc`/etc. in `app.html`'s `<style>`).

- **`backend.jl`** — reads/writes `config.toml` (comment-preserving, validated),
  imports measured CSVs, runs any stage as a streamed subprocess, stops the current
  run, opens folders, reads/writes presets. `POSITIVE_KEYS` (must be > 0) includes
  `magnet_Br_T` and `magnet_side_mm`.
- **`server.jl`** — HTTP endpoints (`/api/config`, `/api/measured`, `/api/import`,
  `/api/run` [streams the live log], `/api/stop`, `/api/presets`, `/api/open_folder`).
- **`app.html`** — a top iteration-name box, then per-stage blocks: **Stage 0**
  (measured data + geometry preset + field adapter + `eval_domain` grid/shell +
  `shell_source` measured/SH + `auto` direction + a "Shim magnets" panel for
  `magnet_Br_T` / `magnet_side_mm` / `initial_angle_deg` with a live derived-μ
  read-out), **Stage 1** (task selector: Grad build+solve / Grad L-curve / SA
  optimize / SA L-curve / Ring search / Insert search — each shows only its
  parameters; SA hides in shell mode), **Stage 1.5** (OSII import: pick an OSII file
  + angle offset/invert → shim CSV), **Stage 2** (insert preset + params — including
  `letter_thickness` and `label_scale`, both editable — with **Build STL only** for
  the OSII / no-optimizer path), **Stage 3** (viewers with **Save GIF** buttons,
  open-folder, and a **ring-placement table** showing where each printed
  `Ring_<InsertPos>` (e.g. `Ring_N07`) mounts *and which trays actually carry
  magnets*, read from the shim CSV via `/api/placement` — so a sparse layout is not
  mistaken for a full ring). A pinned run log with **Stop** streams output live;
  parameter labels are bold with one-line descriptions.

### Repository layout

```
config.toml  Project.toml  Manifest.toml  pipeline_config.jl   ← stay at the root
    config.toml        ← edit this (or use the GUI)
    pipeline_config.jl ← reads config.toml, derives paths + geometry
run_pipeline.jl        ← orchestrator (Stage 0→1→1.5→2→3→4)
install_deps.jl        ← pins the Julia project
README.md              ← plain-language guide (start here)

stages/
  stage0_field/      Field_data_file_adapter.jl    (regular grid → grid)
                     Field_data_SH_interpolator.jl (shell scan → grid, SH fit)
                     Field_data_shell.jl           (any scan → shell at Rmax, SH fit; + grid for viewers)
  stage1_optimize/   setup.jl / setup_shell.jl     (evaluation context: grid mesh / shell points + magnet positions)
                     sim_annealing_optim/  operation.jl, run_optim.jl, run_lcurve.jl, benchmark.jl
                     grad_optim/           grad_math.jl, grad_core.jl, optim_grad.jl, run_grad.jl,
                                           run_grad_lcurve.jl, ring_search.jl, ring_combos.jl, insert_search.jl
  stage1_5_export/   export_csv.jl     (optimizer result → shim CSV; honours final_state)
                     osii_to_shim.jl   (ALT: OSII layout → shim CSV; skips Stages 0–1)
  stage2_stl/        CSV_to_STL.jl     (Gmsh geometry)
  stage3_viewers/    Shimming_magnets_visualizer.jl (3D)   field_slice_viewer.jl (slice)
                     (both run field-only when no shim CSV exists)
  stage4_verifier/   python_verifier.jl  (adapter; launches stages/stage4_verifier/Shimming_verifier/run_verifier.py)
                     Shimming_verifier/  standalone Python (magpylib): main.py, run_verifier.py,
                       measurement_io, shim_magnets, field_analysis, viewer_2d/3d, sh_pyramid,
                       requirements.txt (+ its own Field_measurements/, Shimming_magnets/, output/)

core/    kernels/  f_kernel.jl (field), op_kernel.jl (SA mutation)
         utils/    read_measured, sh_select, grid_utils, pos_trays, wrap, ppm_report, imanes,
                   helping_functions_for_JIG, verify_solution, eval_metrics, viewer_frame
tools/   make_halbach_ring_csv.py   ← test tool: Halbach-dipole "bits" shim CSV (see below)
gui/     backend.jl, server.jl, app.html, presets.json
assets/  Magnet_Inserts_Models_stl_step/ , Static_Inserts_Models_stl_step/   base inserts

data/
  inputs/   data/inputs/Measured_Field_Data_csv/           input scans
            data/inputs/OSII_shimming_outputs_toconvert/   OSII layout CSVs (input to osii_to_shim.jl)
  cache/    data/cache/Interpolated_Field_Data_jld2/      Stage 0 output (grid + _shell maps)
  outputs/  Optimizer_Output_per_Iteration/<ITER>/
                <ITER>_BOOST_result.jld2        active Stage-1 result (last optimizer to run)
                <ITER>_SA_result.jld2           SA's copy      ┐ never clobber each other →
                GradOpt/grad_result.jld2        gradient's copy ┘ SA vs grad comparable
                GradOpt/operator_G.jld2         cached linear operator
                GradOpt/ring_operator.jld2      cached ring operator (SHARED: ring + insert search)
                InsertSearch/insert_result.jld2 insert search's copy (sparsity in final_state)
                Viewers/                        Stage-3 "Save GIF" output (viewer_gif_subdir)
                PythonVerifier/                 Stage-4 output (verifier_output_subdir)
                SHDecomposition/sh_decomposition.csv   Stage-0 SH coefficients (SH + shell adapters)
                Lcurve/, GradOpt/Lcurve/, RingSearch/, InsertSearch/, Benchmark/, imgs/
                <ITER>_shim.csv                 the seam (→ Stage 2); SPARSE after an insert search
                SPARSE_LAYOUT.marker            written by osii_to_shim; export_csv refuses to clobber
            Final_3D_printing_outputs_per_Iteration/<ITER>/Ring_<InsertPos>/{stl_outputs,Step_outputs}
                (folder/file names use the P/N sign token, e.g. Ring_N07, RingN07_Tray03.stl —
                 InsertPos is the real, physical, signed tray slot, not a sequential index)
```

Companion doc (in the repo root):
- `README.md` — a plain-language guide (no programming needed) to the OSII import,
  measured-shell scoring, and the ring search, with a glossary and click-by-click steps.

---

## Part III — What has been done

### Verified on the GPU box
- **Gradient optimizer** reaches the global optimum (parallelepiped scan: 7878 ppm;
  operator `G` rel. err 4e-8; 10/10 identical L-BFGS restarts).
- **Hardware limit confirmed:** the global optimum still leaves ~7878 ppm (vs 11163
  with no shims) — shims correct ~29% of the spread; the remaining lever is physical.
- **Ring search:** exhaustive n=2 on the Josh spherical scan → best pair (trays −2,
  +3), 17814.8 ppm, and an independent full grad solve on those two rings reproduces
  17814.8 **exactly**.
- Variance / soft-range gradient formulas pass finite-difference checks (~1e-7).

### Built + statically checked, not yet run on the GPU box
- **Shell mode** (`eval_domain = "shell"`): `Field_data_shell.jl`, `setup_shell.jl`,
  shell-tagged operator, `grad_core` shell branch, and the grid-for-viewers output.
  Confirm ppm ≈ a grid run (should match, since the shell captures boundary extrema),
  and that `Rmax` = the measured shell radius.
- **Controlled-CSV reader + auto direction**: `utils/read_measured.jl` verified
  against the actual files (Controlled scan → 1742 averaged points, auto-detects +x;
  Josh scan → 7082 points). Needs a live Stage-0 run to confirm.
- Greedy ring search at larger *n* (mechanism verified at n=2).

### Recent additions
- Two-optimizer split (SA vs gradient) with a config toggle + comparison tools.
- Gradient objective generalized (variance / soft-range / Tikhonov ∇B term).
- Ring search (greedy + exhaustive) with a spots-between constraint.
- The browser GUI (per-stage, live log, Stop, presets, ring-placement table).
- Shell-based evaluation; native Controlled-CSV reading with auto direction.
- **OSII import** (`osii_to_shim.jl`): convert an external OSII magnet layout into the
  Stage-1.5 shim CSV (frame remap, metres→mm, angle inverted + 90° offset), skipping
  Stages 0–1; GUI "Build STL only" feeds it to Stage 2. Iteration name/number carry
  through to the printed inserts.
- **Measured-shell scoring** (`shell_source = "measured"`, now default): score the raw
  measured points, not the SH-smoothed resample (~200 ppm more honest on the ref scan).
- **Ring search ~30× faster**: solve in Float64 (BLAS + reaches `g_tol`), and rank on a
  ~250-point sub-shell with the winner re-solved on the full shell; live "N scored" log.
- **Field-only viewers**: both Stage-3 viewers open on the measured field with no shim
  CSV (inspect homogeneity before shimming); the slice viewer also gained zoom-preserving,
  region-aware ppm + profile clipping, and a finer field grid (`sh_grid_n`, 5 mm default).
- **Insert search** (`grad_optim/insert_search.jl`): sequential per-insert placement
  driven by a magnet budget, sharing the ring operator; sparse output carried through
  the pipeline by `final_state`.
- **Magnet strength is configurable** — `magnet_Br_T` (remanence) + `magnet_side_mm`
  (cube side length) instead of hardcoded in five files in two units;
  `initial_angle_deg` likewise. (An intermediate `magnet_B1cm_mT` on-axis-field-at-1cm
  proxy was tried and then replaced by the Br/side pair, which needs no calibration
  distance; `magnet_B1cm_mT`/`B1CM_T` now survive only as derived back-compat values.)
- **GIF export from both Stage-3 viewers** — a rotating-camera GIF (3D viewer) or a
  slice-sweep GIF (slice viewer), each with a single-view button and a "Measured vs
  Shimmed" pair-comparison button, via `Makie.record` (explicitly qualified to avoid
  the CUDA/GLMakie `record` name clash). Config: `viewer_gif_frames`,
  `viewer_gif_fps`, `viewer_gif_subdir`.
- **GUI: `label_scale` + editable `letter_thickness`** — Stage 2 now exposes both the
  overall size of the engraved label digits (`label_scale`) and the engraving depth
  (`letter_thickness`) as editable fields; header/palette also refreshed to "BOOST —
  B0 Optimization Shimming Technique" / "Low Field MRI Project UC" on a light-green theme.
- **Stage 4 — independent Python verifier** (`python_verifier.jl` +
  `stages/stage4_verifier/Shimming_verifier/run_verifier.py`): inputs are just the measured field, the shim
  layout and what to run; wired into `run_pipeline.jl` (`run_python_verifier`,
  `start_stage = 5`), `config.toml` and a GUI Stage-4 block. Handles the optimizer-vs-scan
  frame rotation. Ran end-to-end on the reference iteration (9562 ppm vs the optimizer's
  9483).
- **Independent front/back tray shifts** (`front_tray_shift_mm`, `back_tray_shift_mm`,
  `tray_slot_spacing_mm`) replace the symmetric `half_shift_mm`; both viewers now read
  the config values instead of hardcoding 0.0.
- **`export_csv.jl` honours `final_state`** — it exported every magnet regardless of
  the on/off mask, which mis-exported any sparse or partially-switched-off solution.
- **RingNumber is now the real, physical InsertPos everywhere**, not a 0-based
  sequential index — `export_csv.jl`, `insert_search.jl`, `osii_to_shim.jl`,
  `CSV_to_STL.jl`, the GUI, and both Stage-3 viewers all derive/consume it directly
  from the physical tray slot; printed parts and folder/file names spell the sign as
  a letter token (`N`/`P`) instead of `+`/`-`. Fixed two real display/positional
  bugs along the way (the GUI table's lookup key, and both viewers' z/legend
  derivation).
- **Coordinate-frame handling** (see "Coordinate frames"): `shim_csv_frame` (default `scan`) rotates the shim
  CSV back to the scan frame at export; `viewer_frame` (default `scan`) draws both viewers in the scan frame
  with a signed field; `utils/viewer_frame.jl` holds the shared helpers; the verifier reads the CSV as
  written (`--shim-frame lab`).
- **Halbach test bits** — `make_halbach_ring_csv.py` (see above) for axis/angle-convention checks.
- Cleanup: removed dead code (`pipeline_config_WORKING.jl`, orphan utils) and stale
  plan docs; this reference and `README.md` are the source of truth.

### Halbach test bits — `make_halbach_ring_csv.py` (axis / angle-convention checks)

Builds a shim CSV (`X, Y, RingNumber, Angle`, plus a `_shim_xyz.csv` with the literal Z) of ideal
Halbach-dipole **bits** to check the pipeline's x/y/z and angle conventions in the viewers, the verifier
and Stage 2 — no optimizer needed. Options: `--OSII_version OSII1|OSII2` (geometry from `gui/presets.json`:
OSII2 = V2.1, r 231 mm, 20.64°/insert, field **+y**; OSII1 = V1.1, r 277 mm, 18°/insert, field **+x**),
`--tray_number` (int, `3,4` or `all`), `--z_center` *or* `--slot_center`, `--z_copies` (odd), `--flip`
(reverse the field), `--out`. Angle rule (ideal Halbach, optimizer convention θ from +x toward +y):
field +x → θ = 2φ, field +y → θ = 2φ − 90° (φ = polar angle of the magnet). `--z_center` copies sit at
`z_center + k·spacing` and each must land on a real tray slot (no slot at z = 0 unless a tray shift is 0);
`--slot_center` takes consecutive *real* slots (slot 0 is skipped). Warns if `config.toml`'s geometry
differs from the chosen preset. To build STLs from such a CSV: put it at
`data/outputs/Optimizer_Output_per_Iteration/<ITER>/<ITER>_shim.csv` under a **new** iteration name and click
**Build STL only** (never "Export + build STL" — it needs an optimizer result and would overwrite it).

### Known gaps vs. the Shimmer / OSII² preprint (arXiv 2608.22351; reviewed, NOT implemented)

A read-through of the "Shimmer" preprint against these docs (not against the code) found these gaps, most
important first:
1. **No measure → install → re-measure loop.** Shimmer iterates 3–6 times and loads the existing shim
   configuration; here a run is one-shot and nothing handles a field map measured *with* shims installed
   (subtract/freeze installed magnets, exclude occupied slots). The ~9.5k-ppm result is not an end state.
2. **Model ≠ reality, and Stage 4 only checks model vs model.** Paper: predicted vs measured total ppm
   matched (21,225 vs 21,295) but point-by-point error was up to 3,522 ppm. Their 1000-ppm tolerances for
   shims: rotation ≤ 2°, position ≤ 3 mm, Br ≤ 3 %. Here one global `magnet_Br_T`, cube side tolerance
   (moment ∝ side³), no sensitivity/Monte-Carlo study, no post-install measured-vs-predicted comparison.
3. **Temperature.** NdFeB ≈ −1200 ppm/K; a 0.9 K drift over an 8 h scan ≈ 600 ppm, and a spiral scan turns
   the drift into a spatial pattern the optimizer would try to cancel. Temperature is read but unused.
4. **Probe noise / metric.** Hall 821 ppm vs NMR 316 ppm on the same sphere; the default scores raw
   max−min of measured |B| (noise inflates ppm; the optimizer partly fits noise); |B| vs the B0 component.
5. **Frames / physical orientation.** OSII angle sign/offset still unresolved; Stage 4 cannot catch the
   physical insert orientation; scan-centre vs magnet-centre / tray z-origin offsets; no pole marker on the
   printed holders (the paper engraves one).
6. **Objective / "hardware limit".** Variance is minimised but the figure of merit is range; the unreachable
   main-array ring pattern (n ≈ 6) may be a structural floor; optimising a larger DSV worsens smaller ones;
   magnet size is not a degree of freedom here.

### Frame handling — what was tested (this session)
- **Independent frame check** (Python dipole model on the raw scan `06102026_UCScanner_NoShimming`, mean
  field (−0.4, −42.2, −3.6) mT → B0 along −y; unshimmed |B| = 19,155 ppm): the optimizer's CSV placed in the
  scan frame **with** the 180° back-rotation (positions + moments) gives **9,601 ppm**; used as if already in
  the scan frame 28,830; moments not rotated 33,861. A z-flip changed it only to 9,844 (the rings are nearly
  z-symmetric, so a **z mirror cannot be detected** this way). Conclusion: the optimizer ↔ scan frame
  conversion is self-consistent; no rotation bug found.
- `utils/viewer_frame.jl: grid_to_scan` checked against a pointwise coordinate map for all four directions
  (base Julia, synthetic arrays).
- `make_halbach_ring_csv.py`: full 12-tray ring gives a centre field of **221 µT along +y (OSII2)** and
  **128 µT along +x (OSII1, r 277 mm)** (own dipole sum, Br 1.26 T / 6 mm); z → InsertPos mapping and the
  invalid-slot error exercised; the `Halbach_Tests` iteration's verifier input shows tray 3 (slot −6) at
  z = −50…−70 mm in the scan frame.
- All edited Julia files parse (`Meta.parseall`).
- **NOT run:** `export_csv.jl` / `insert_search.jl` with the new rotation, Stage 2 on a rotated CSV, the viewers
  with `viewer_frame`/signed display (GLMakie/CUDA box), `python_verifier.jl` in `lab` mode, any GUI change.
- Environment note: on the Windows dev box Julia packages fail to load (Application Control blocks the
  unsigned compiled `.dll` caches in `~/.julia/compiled`); run the GUI/pipeline on the GPU box or WSL2, or have
  IT allowlist the depot.

### Environment
The pipeline needs the NVIDIA/CUDA box for Stage 1 and the viewers. Code edits in
recent sessions were verified statically (no GPU/Julia in the editing sandbox); runs
are launched on the GPU box.

### Extending
- More rings: raise `ring_search_n` (greedy scales linearly); watch
  `RingSearch/ring_search.png` (ppm vs #rings) for where it plateaus.
- Hardware what-ifs: change `shim_radius_mm`, `magnet_Br_T`/`magnet_side_mm` (μ),
  rings, or `Rmax`, then re-run `optim_grad.jl` + `run_grad.jl` for the new
  achievable floor.
- Not built yet: convex lower bound (Convex.jl + SCS), CMA-ES baseline, greedy ring
  search that folds already-placed rings into the base field, temperature correction.

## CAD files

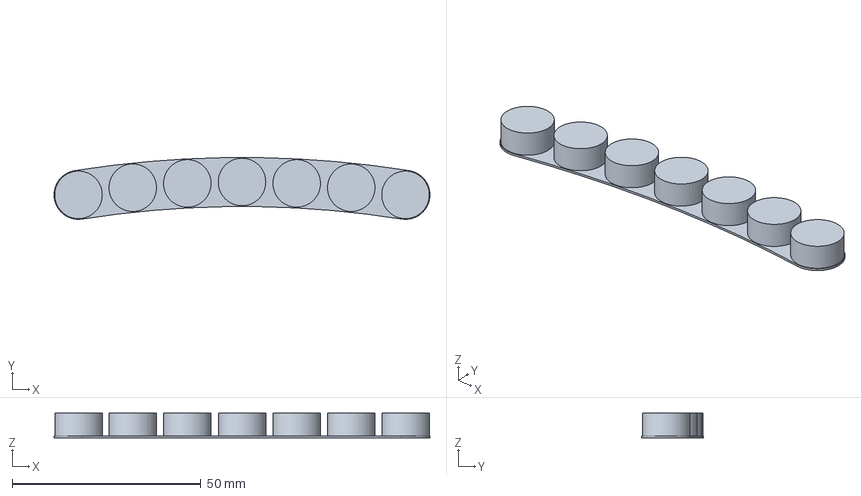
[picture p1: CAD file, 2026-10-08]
assets/Magnet_Inserts_Models_stl_step/MagnetInsert_radius_277.0radius_7mags.step
99.7 x 16.4 x 6.50 mm

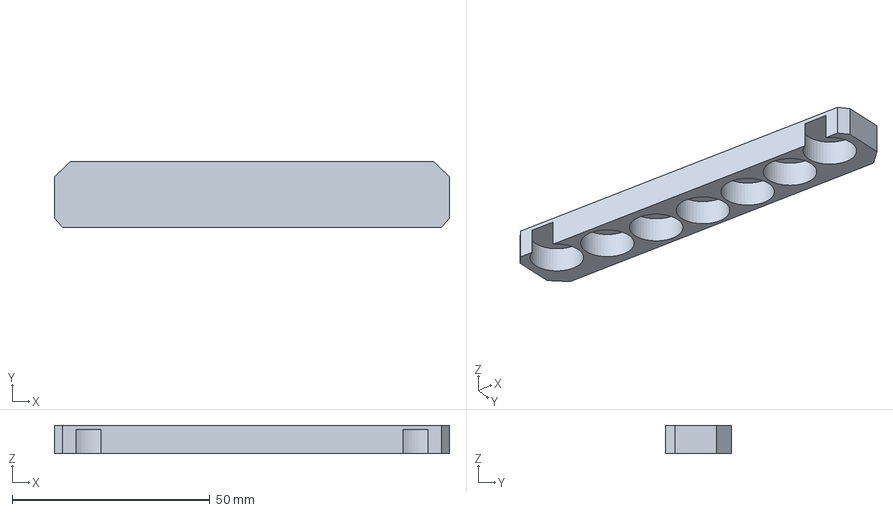
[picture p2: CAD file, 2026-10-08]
assets/Static_Inserts_Models_stl_step/StaticInsert_radius_231.0radius_7mags.step
100.0 x 16.6 x 7.10 mm

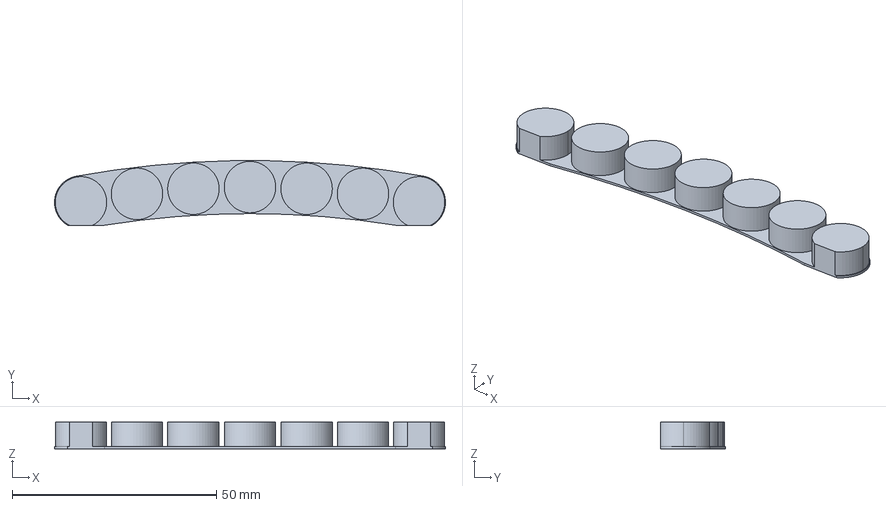
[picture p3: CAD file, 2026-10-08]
assets/Magnet_Inserts_Models_stl_step/MagnetInsert_radius_231.0radius_7mags.step
95.7 x 15.8 x 6.50 mm

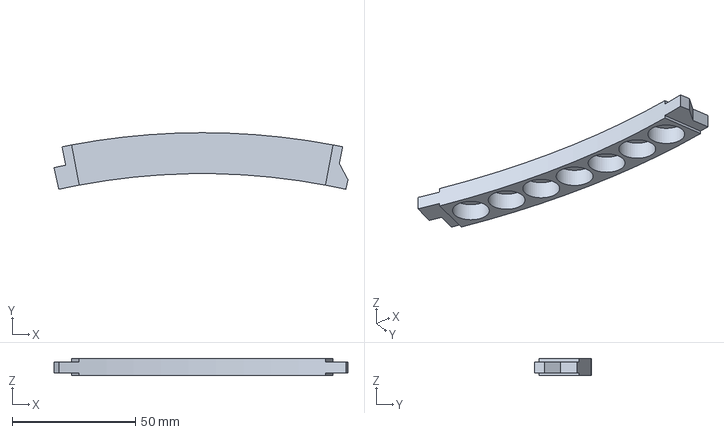
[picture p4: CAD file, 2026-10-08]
assets/Static_Inserts_Models_stl_step/StaticInsert_radius_277.0radius_7mags.step
119.3 x 23.0 x 7.00 mm

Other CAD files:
assets/Magnet_Inserts_Models_stl_step/MagnetInsert_radius_231.0radius_7mags.stl
assets/Magnet_Inserts_Models_stl_step/MagnetInsert_radius_277.0radius_7mags.stl
assets/Static_Inserts_Models_stl_step/StaticInsert_radius_231.0radius_7mags.stl
assets/Static_Inserts_Models_stl_step/StaticInsert_radius_277.0radius_7mags.stl

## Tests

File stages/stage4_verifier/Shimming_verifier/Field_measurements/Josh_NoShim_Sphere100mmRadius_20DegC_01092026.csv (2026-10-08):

Fecha y Hora | 2026-09-01 20:42:02
Medidor | VGM_GAUSSMETER
Firmware | AL-PRG-0VGM-01 4.01
Muestras por punto | 5
T estabilizacion (s) | 5
Velocidad (mm/min) | 1000
Radio maximo (mm) | 100
Paso radial (mm) | 100
Resol theta (deg) | 6
Resol phi (deg) | 6
Sentido cascarones | afuera_dentro
Timestamp | radio | theta_deg | phi_deg | X | Y | Z | T_robot (C) | muestra | Time (s) | x axis (gauss) | y axis (gauss) | z axis (gauss) | Magnitude (gauss)
2026-09-01 20:42:13.988 | 0.0 | 0.0 | 0.0 | 0.0 | 0.0 | 0.0 |  | 1 | 0.25 | 427.19 | 157.66 | 57.78 | 459.0
2026-09-01 20:42:14.243 | 0.0 | 0.0 | 0.0 | 0.0 | 0.0 | 0.0 |  | 2 | 0.5 | 427.19 | 157.66 | 57.78 | 459.0
2026-09-01 20:42:14.482 | 0.0 | 0.0 | 0.0 | 0.0 | 0.0 | 0.0 |  | 3 | 0.75 | 427.16 | 157.67 | 57.77 | 458.98
2026-09-01 20:42:14.737 | 0.0 | 0.0 | 0.0 | 0.0 | 0.0 | 0.0 |  | 4 | 1.0 | 427.16 | 157.67 | 57.77 | 458.98
2026-09-01 20:42:14.993 | 0.0 | 0.0 | 0.0 | 0.0 | 0.0 | 0.0 |  | 5 | 1.25 | 427.19 | 157.65 | 57.79 | 459.0
2026-09-01 20:42:28.862 | 100.0 | 0.0 | 0.0 | 0.0 | 0.0 | 100.0 |  | 1 | 0.25 | 427.54 | 157.6 | 58.08 | 459.34
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

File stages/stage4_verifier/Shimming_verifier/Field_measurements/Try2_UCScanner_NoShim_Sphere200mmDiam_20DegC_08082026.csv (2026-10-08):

Fecha y Hora | 2026-08-08 14:36:33
Medidor | VGM_GAUSSMETER
Firmware | AL-PRG-0VGM-01 4.01
Muestras por punto | 5
T estabilizacion (s) | 2.5
Velocidad (mm/min) | 1000
Radio maximo (mm) | 100
Paso radial (mm) | 100
Resol theta (deg) | 6
Resol phi (deg) | 6
Sentido cascarones | adentro_afuera
Timestamp | radio | theta_deg | phi_deg | X | Y | Z | T_robot (C) | muestra | Time (s) | x axis (gauss) | y axis (gauss) | z axis (gauss) | Magnitude (gauss)
2026-08-08 14:36:41.099 | 0.0 | 0.0 | 0.0 | 0.0 | 0.0 | 0.0 | 18.0 | 1 | 0.25 | -21.12 | 468.91 | -15.78 | 469.65
2026-08-08 14:36:41.339 | 0.0 | 0.0 | 0.0 | 0.0 | 0.0 | 0.0 | 18.0 | 2 | 0.5 | -21.12 | 468.91 | -15.78 | 469.65
2026-08-08 14:36:41.595 | 0.0 | 0.0 | 0.0 | 0.0 | 0.0 | 0.0 | 18.0 | 3 | 0.75 | -21.13 | 468.88 | -15.77 | 469.62
2026-08-08 14:36:41.850 | 0.0 | 0.0 | 0.0 | 0.0 | 0.0 | 0.0 | 18.0 | 4 | 1.0 | -21.13 | 468.88 | -15.77 | 469.62
2026-08-08 14:36:42.090 | 0.0 | 0.0 | 0.0 | 0.0 | 0.0 | 0.0 | 18.0 | 5 | 1.25 | -21.14 | 468.88 | -15.77 | 469.62
2026-08-08 14:36:53.973 | 100.0 | 0.0 | 0.0 | 0.0 | 0.0 | 100.0 | 18.9 | 1 | 0.25 | -21.5 | 468.8 | -16.37 | 469.57
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

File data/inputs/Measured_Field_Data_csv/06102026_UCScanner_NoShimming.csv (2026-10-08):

Fecha y Hora | 2026-10-06 18:33:26
Medidor | VGM_GAUSSMETER
Firmware | AL-PRG-0VGM-01 4.01
Muestras por punto | 10
T estabilizacion (s) | 2
Velocidad (mm/min) | 500
Radio maximo (mm) | 100
Paso radial (mm) | 100
Resol theta (deg) | 8
Resol phi (deg) | 8
Sentido cascarones | afuera_adentro
Sensores temperatura | 1
Timestamp | radio | theta_deg | phi_deg | X | Y | Z | T_robot (C) | muestra | Time (s) | x axis (gauss) | y axis (gauss) | z axis (gauss) | Magnitude (gauss)
2026-10-06 18:33:32.339 | 0.0 | 0.0 | 0.0 | 0.0 | 0.0 | 0.0 | 22.125 | 1 | 0.25 | -4.21 | -421.8 | -36.2 | 423.37
2026-10-06 18:33:34.845 | 0.0 | 0.0 | 0.0 | 0.0 | 0.0 | 0.0 | 22.125 | 2 | 0.5 | -4.21 | -421.81 | -36.2 | 423.38
2026-10-06 18:33:35.100 | 0.0 | 0.0 | 0.0 | 0.0 | 0.0 | 0.0 | 22.125 | 3 | 0.75 | -4.21 | -421.81 | -36.2 | 423.38
2026-10-06 18:33:35.356 | 0.0 | 0.0 | 0.0 | 0.0 | 0.0 | 0.0 | 22.125 | 4 | 1.0 | -4.21 | -421.79 | -36.22 | 423.36
2026-10-06 18:33:35.597 | 0.0 | 0.0 | 0.0 | 0.0 | 0.0 | 0.0 | 22.125 | 5 | 1.25 | -4.21 | -421.79 | -36.22 | 423.36
2026-10-06 18:33:35.852 | 0.0 | 0.0 | 0.0 | 0.0 | 0.0 | 0.0 | 22.125 | 6 | 1.5 | -4.2 | -421.8 | -36.21 | 423.37
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

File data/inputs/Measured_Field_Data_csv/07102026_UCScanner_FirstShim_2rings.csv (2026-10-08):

Fecha y Hora | 2026-10-07 11:22:05
Medidor | VGM_GAUSSMETER
Firmware | AL-PRG-0VGM-01 4.01
Muestras por punto | 10
T estabilizacion (s) | 2
Velocidad (mm/min) | 500
Radio maximo (mm) | 100
Paso radial (mm) | 100
Resol theta (deg) | 8
Resol phi (deg) | 8
Sentido cascarones | afuera_adentro
Sensores temperatura | 0
Timestamp | radio | theta_deg | phi_deg | X | Y | Z | T_robot (C) | muestra | Time (s) | x axis (gauss) | y axis (gauss) | z axis (gauss) | Magnitude (gauss)
2026-10-07 11:22:09.832 | 0.0 | 0.0 | 0.0 | 0.0 | 0.0 | 0.0 | 22.25 | 1 | 0.25 | -2.68 | -424.56 | -36.03 | 426.09
2026-10-07 11:22:10.087 | 0.0 | 0.0 | 0.0 | 0.0 | 0.0 | 0.0 | 22.25 | 2 | 0.5 | -2.69 | -424.51 | -36.03 | 426.04
2026-10-07 11:22:10.327 | 0.0 | 0.0 | 0.0 | 0.0 | 0.0 | 0.0 | 22.25 | 3 | 0.75 | -2.69 | -424.51 | -36.03 | 426.04
2026-10-07 11:22:10.583 | 0.0 | 0.0 | 0.0 | 0.0 | 0.0 | 0.0 | 22.25 | 4 | 1.0 | -2.68 | -424.55 | -36.04 | 426.08
2026-10-07 11:22:10.838 | 0.0 | 0.0 | 0.0 | 0.0 | 0.0 | 0.0 | 22.25 | 5 | 1.25 | -2.68 | -424.55 | -36.04 | 426.08
2026-10-07 11:22:11.078 | 0.0 | 0.0 | 0.0 | 0.0 | 0.0 | 0.0 | 22.25 | 6 | 1.5 | -2.69 | -424.57 | -36.03 | 426.1
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

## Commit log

2026-10-08 Initial commit: BOOST shimming pipeline
    [06102026_UCScanner_NoShimming.csv, 07102026_UCScanner_FirstShim_2rings.csv, Josh_NoShim_Sphere100mmRadius_20DegC_01092026.csv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]
2026-10-08 Reorganize repository into stages/, core/, docs/, tools/, assets/, data/
    Move loose root files into the new layout (stage folders follow the docs'
    numbering: viewers = stage3, verifier = stage4). Update include/activate
    paths, pipeline_config directory constants, run_pipeline and GUI script
    paths, .gitignore, and docs. No logic changes; not yet run end to end.
    [06102026_UCScanner_NoShimming.csv, 07102026_UCScanner_FirstShim_2rings.csv, Josh_NoShim_Sphere100mmRadius_20DegC_01092026.csv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]
2026-10-08 Tidy docs and redesign GUI as a no-scroll tabbed layout
    Docs: move USER_GUIDE.md to the root; stop tracking GRAD_OPTIMIZATION.md
    and HANDOFF.md (kept locally under the ignored docs/); drop README links
    to them.
    GUI: stage tabs under the iteration bar, run log as a slim right-hand
    column, folder shortcuts in a bottom bar, Stage 0 split into sub-tabs so
    every stage fits the window. New open_folder targets: viewers, osii,
    cache, assets.
2026-10-12 GUI: merge stages into three tabs and refine layouts
    - Stage 0 shows all panels at once (scrolls inside its panel), with Shim
    magnets beside Measured data
    - Stages 1, 1.5 and 2 share one tab (1 and 1.5 side by side at equal
    height, 2 underneath)
    - Viewers (3) and Python verifier (4) share one tab, side by side
    - Variable names no longer wrap
2026-10-26 Honour occupied rings, move Export to Stage 1, add BOOST-frame pass-through
    - Occupied rings (positions_in_tray_occupied) are now excluded from the ring
    search / insert search candidates and dropped (with a warning) from the
    wished list; they were previously ignored everywhere.
    - GUI: "Export shim CSV" moves to the Optimize box; Stage 2 has a single
    "Build STL" button. README, technical reference and script messages updated.
    - osii_to_shim.jl auto-detects BOOST X/Y/Z(mm) and seam-format CSVs and passes
    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
2026-10-26 Update run config, presets, regenerated insert models and new input scans
    - config.toml: new iteration (AllInOne_6ringShim), 6 wished rings, no occupied
    rings, 840 magnets, new measured field map and OSII input
    - gui/presets.json: edited presets
    - assets: regenerated 231 mm and 277 mm magnet/static insert STEP models
    - data/inputs: new measured scans (Josh/UC scanner) and the ring-pairs shim xyz
2026-10-29 Add already-placed shims, native file pickers, hidden ring list; show placed shims in viewers
    - New "Already placed shims" (0, 1 or several shim CSVs) in Stage 0 → Measured data, replacing
    positions_in_tray_occupied. core/utils/placed_shims.jl reads seam/xyz CSVs, converts the scan frame
    to the optimizer frame and derives occupied (ring, tray) slots. The scan is assumed to include the placed
    shims, so they only block slots: insert search skips those slots (+ same-tray spacing), ring search skips
    whole rings that hold one or are too close. The ring-operator cache is unaffected.
    - Scan / OSII / placed-shim imports use the browser's native file dialog (upload endpoint) instead of
    ty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
